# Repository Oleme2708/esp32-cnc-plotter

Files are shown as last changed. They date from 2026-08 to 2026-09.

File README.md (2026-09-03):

# ✏️ ESP32 CNC Plotter






A fully 3D-printed three-axis CNC drawing machine controlled by an ESP32.  
The machine receives G-code from **Universal Gcode Sender (UGS)** and uses **Grbl_ESP32** to control three 28BYJ-48 unipolar stepper motors through ULN2003 driver boards.

# Note

This project was developed using **PlatformIO in Visual Studio Code**.

The mechanical structure is based on the **Simple Arduino CNC Plotter** design by **DonTheMaker**.  
The original design uses a fully 3D-printed mechanical structure together with stepper motors and a small number of fasteners.

For my build, I replaced the original controller setup with an **ESP32**, configured **Grbl_ESP32** for three unipolar stepper motors, and used **Universal Gcode Sender** to manually control the axes and run G-code file.

I also designed two additional washer parts because the screws available to me did not fit the original assembly as required.

> CAD source link: https://makerworld.com/en/models/2889145-simple-arduino-cnc-plotter?from=search#profileId-3227843

# Demo

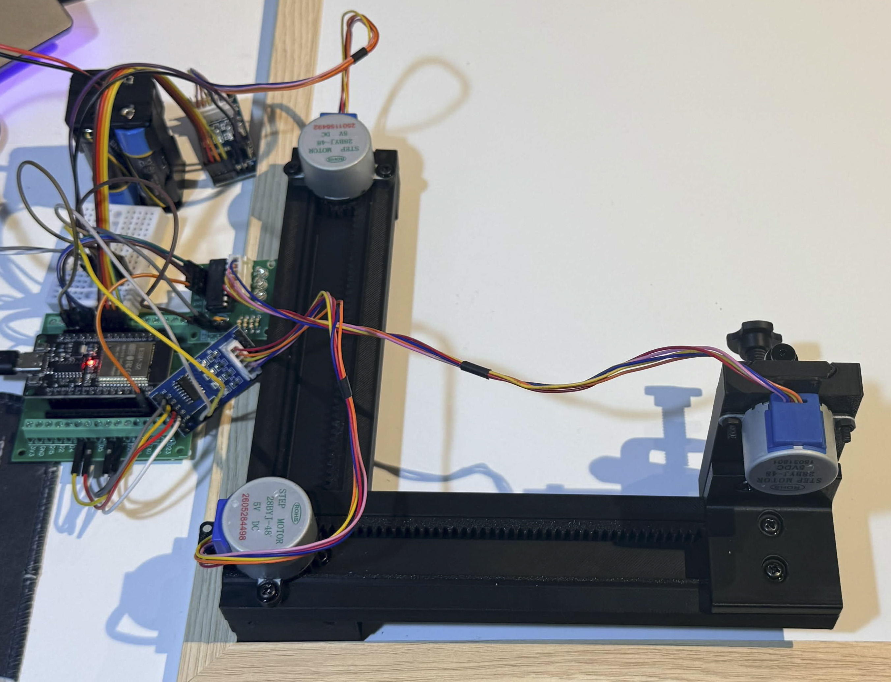
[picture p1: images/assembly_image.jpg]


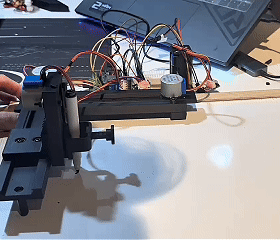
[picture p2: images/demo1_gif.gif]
CNC Plotter Demo


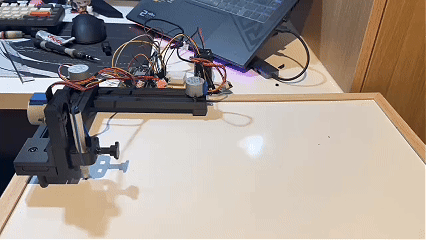
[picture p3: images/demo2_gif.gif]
CNC Plotter Demo


# Project overview

This project is a small three-axis CNC pen plotter built around an ESP32 and three 28BYJ-48 5V stepper motors.

The machine is controlled through the following system:

```text
G-code file
     |
     v
Universal Gcode Sender (UGS)
     |
     USB / Serial
     v
ESP32 + Grbl_ESP32
     |
     v
ULN2003 motor drivers
     |
     v
28BYJ-48 stepper motors
     |
     v
X / Y / Z mechanical movement
     |
     v
Pen drawing on paper
```

UGS is used to:

+ Calibration and setup
+ Jog the X, Y and Z axes manually
+ Send individual G-code commands
+ Preview G-code paths
+ Load complete G-code files
+ Start and monitor drawing jobs

The X and Y axes control the pen position on the paper, while the Z axis lifts and lowers the pen.

The current usable drawing area is approximately:

```text
125 mm × 125 mm
```

# Features

+ Fully 3D-printed CNC plotter structure
+ Three-axis motion control
+ ESP32-based controller
+ Three 28BYJ-48 unipolar stepper motors
+ Three ULN2003 motor drivers
+ Custom Grbl_ESP32 machine configuration
+ G-code control using Universal Gcode Sender
+ Manual X/Y/Z jogging through UGS
+ G-code preview and job execution
+ PlatformIO development

# Hardware

+ ESP32 development board
+ 3 × 28BYJ-48 5V stepper motors
+ 3 × ULN2003 stepper motor driver boards
+ External regulated 5V power supply
+ Fully 3D-printed CNC plotter structure
+ Pen / marker
+ Jumper wires
+ USB cable
+ Small number of M4 screws / fasteners used in the mechanical assembly
+ 2 × custom 3D-printed washers added for my build

# Software

+ Visual Studio Code
+ PlatformIO
+ Universal Gcode Sender (UGS)
+ Grbl_ESP32

## Universal Gcode Sender

UGS is the main interface used to control this CNC plotter from the computer.

Official website:

https://winder.github.io/ugs_website/

UGS is used for manual jogging, sending G-code commands, previewing tool paths, and running complete G-code jobs.

## Grbl_ESP32

This project uses the open-source Grbl_ESP32 firmware by Bart Dring and contributors.

Firmware source:

https://github.com/bdring/Grbl_Esp32

The complete Grbl_ESP32 firmware is not copied into this repository.  
Only the custom configuration used for this machine is included.

# Firmware configuration

The custom machine configuration can be found in:

```text
firmware/esp32_cnc_plotter_config.h
```

The configuration enables unipolar motor control and assigns four ESP32 GPIO pins to each motor.

# ESP32 pin configuration 
These pin are wired this way to avoid important pins that might cause error
## X axis

| Motor phase | ESP32 GPIO |
|---|---:|
| Phase 0 | GPIO 26 |
| Phase 1 | GPIO 25 |
| Phase 2 | GPIO 33 |
| Phase 3 | GPIO 32 |

## Y axis

| Motor phase | ESP32 GPIO |
|---|---:|
| Phase 0 | GPIO 19 |
| Phase 1 | GPIO 16 |
| Phase 2 | GPIO 17 |
| Phase 3 | GPIO 18 |

## Z axis

| Motor phase | ESP32 GPIO |
|---|---:|
| Phase 0 | GPIO 14 |
| Phase 1 | GPIO 27 |
| Phase 2 | GPIO 13 |
| Phase 3 | GPIO 23 |

# Wiring diagram
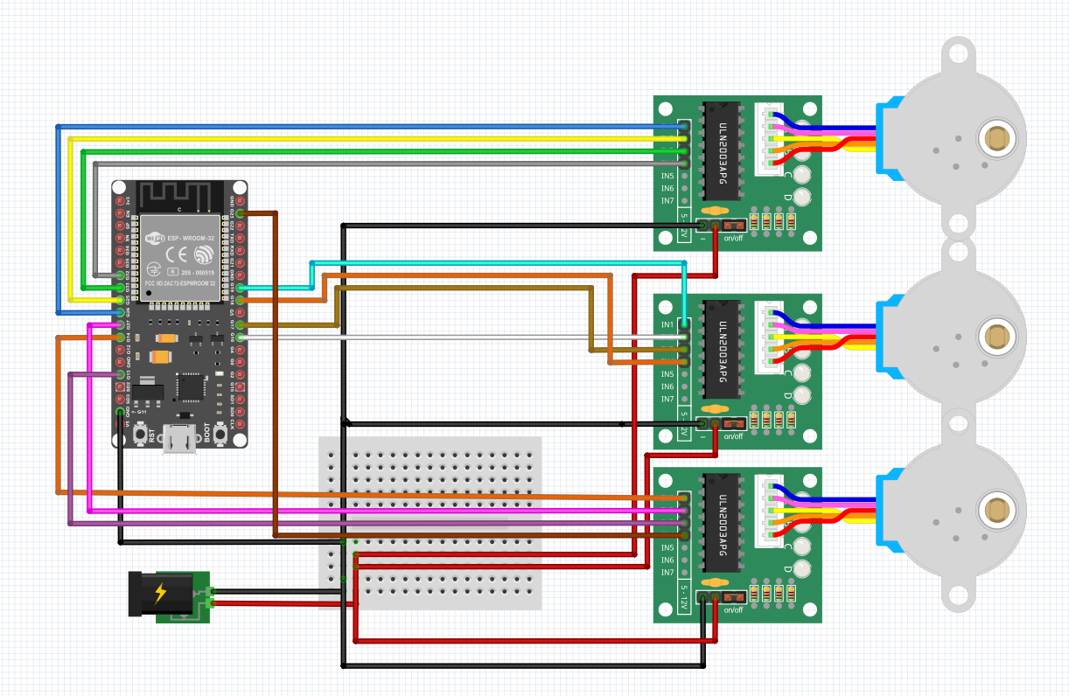
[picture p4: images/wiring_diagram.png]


# Axis direction

The physical orientation of the current machine is:

```text
                 X- (up)
                    ↑
                    |
Y- (left)  ←--------+--------→  Y+ (right)
                    |
                    ↓
                 X+ (down)
```

Therefore:

+ `X+` = move down
+ `X-` = move up
+ `Y+` = move right
+ `Y-` = move left

The Z axis controls pen up / pen down movement.

Because of the physical layout:

```text
Paper vertical direction   = Machine X axis
Paper horizontal direction = Machine Y axis
```

This orientation has to be considered when generating G-code.

# G-code

The machine receives G-code from UGS through the ESP32 serial connection.

Some basic commands used in this project are:

```gcode
G21
G90
G91
```

Where:

```text
G21 = millimetres
G90 = absolute positioning
G91 = relative positioning
```

Example relative movement:

```gcode
G91

G1 X10 F150
G1 X-10 F150

G1 Y10 F150
G1 Y-10 F150
```

With the current machine orientation:

```text
X10  = move 10 mm down
X-10 = move 10 mm up

Y10  = move 10 mm right
Y-10 = move 10 mm left
```

The final drawing tests mainly use `G91` relative positioning because it is easier to start a drawing from a manually selected position without relying on a fixed machine origin.

Custom G-code files are stored in:

```text
gcode/
```

# Pen control

The Z axis lifts and lowers the pen.

Example:

```gcode
G91

G1 Z-1 F20
G1 Y30 F200
G1 Z1 F20
```

Only a small Z movement is required.

The exact pen-up and pen-down distance depends on the mechanical adjustment of the pen holder.

# Calibration

The main Grbl axis calibration settings are:

```text
$100 = X-axis steps/mm
$101 = Y-axis steps/mm
$102 = Z-axis steps/mm
```

The X axis has been tested at approximately:

```text
$100 = 100 steps/mm
```

The calibration method used is:

run G1 X50 F100 to draw a line
measure the line to check the accuracy. The line should be 5cm, changing the value of $100 if different value are drew. repeat for other axis

# Speed testing

The 28BYJ-48 is a small geared stepper motor, so the maximum reliable speed is limited.

Feed rate was increased gradually during testing:

```text
F100
F150
F200
F250
F300
```

If a motor begins to:

+ vibrate without moving
+ lose steps
+ make abnormal sounds
+ fail to return to the original position

the feed rate should be reduced.

# How to Use

## 1. Set up Grbl_ESP32

Clone or download Grbl_ESP32:

https://github.com/bdring/Grbl_Esp32

Copy:

```text
firmware/esp32_cnc_plotter_config.h
```

into:

```text
Grbl_Esp32/src/Machines/
```

Configure the build to use:

```text
-DMACHINE_FILENAME=esp32_cnc_plotter_config.h
```

Then build and upload the firmware to the ESP32 using PlatformIO.

## 2. Connect the machine to UGS

Download / install Universal Gcode Sender:

https://winder.github.io/ugs_website/

Then:

+ Connect the ESP32 to the computer using USB
+ Open UGS
+ Select the correct serial port
+ Set the baud rate to `115200`
+ Connect using GRBL mode

The PlatformIO Serial Monitor must be closed before connecting through UGS because only one application can use the serial port at a time.

## 3. Test the axes

Use the UGS Jog Controller to test:

+ X+
+ X-
+ Y+
+ Y-
+ Z+
+ Z-

Start with a small movement such as 1 mm or 10 mm.

## 4. Run a drawing

+ Move the pen to a safe starting position
+ Make sure enough X/Y travel is available
+ Make sure the pen starts raised
+ Load the `.gcode` file into UGS
+ Check the preview
+ Run a dry test if necessary
+ Start the job

# CAD

The main mechanical structure is based on:

**Simple Arduino CNC Plotter — DonTheMaker**

Platform:

**MakerWorld / Bambu Studio Online Models**

> https://makerworld.com/en/models/2889145-simple-arduino-cnc-plotter?from=search#profileId-3227843

The plotter is designed so that almost the complete mechanical structure can be produced using a 3D printer.

My build uses the original printed mechanism as the base, but the electronics, controller, firmware configuration, wiring, calibration, G-code workflow, and troubleshooting were completed separately for the ESP32 version.

## Additional CAD parts

I designed two simple washer parts for this build because the screws available to me did not fit the original assembly correctly.

Files:

```text
CAD/Washer_1.5mm.STL
CAD/Washer_2mm.STL
```

These washers were used as simple spacing / fitting adjustments during assembly.

The original plotter model is stored in:

```text
CAD/Simple_CNC_Plotter.3mf
```

# What I learned

+ How basic CNC motion control works
+ How G-code controls physical machine movement
+ How to use Universal Gcode Sender to manually control a CNC machine
+ How to preview and execute G-code jobs using UGS
+ How to configure Grbl_ESP32 for a custom machine
+ How to use Grbl_ESP32 with 28BYJ-48 unipolar motors
+ How motor phase order affects direction and movement
+ How to assign ESP32 GPIO pins to three motor axes
+ How to build and upload ESP32 firmware using PlatformIO
+ How to communicate with a CNC controller through serial
+ How to calibrate motion using steps/mm
+ How to test feed rates and detect step loss
+ How to troubleshoot motor-driver and wiring problems
+ How mechanical alignment affects drawing accuracy
+ How to simplify G-code for more reliable motion
+ How to adapt an existing mechanical design to different electronics and available hardware

# Errors and lesson learned

+ **Motor appeared not to move or vibrating:** 
the feed rate was too low, so the motor was moving extremely slowly rather than being completely stopped.
the ULN2003 driver board power connection was disconnected. Checking the driver power fixed the issue.
faulty jumper wires caused unreliable motor phase signals. Replacing the wires restored normal movement.

+ **Motor moved correctly in one direction but vibrated in reverse:** one motor phase connection was unreliable.

+ **Axis direction was incorrect:** with the 28BYJ-48 unipolar motors, the motor phase order and physical wiring directly affect direction.

+ **Drawing orientation was incorrect:** the physical X axis of this machine is vertical while the Y axis is horizontal. The G-code generation logic had to be changed to match the actual machine.

+ **Absolute G-code was harder to manage during testing:** incorrect start positions could cause the machine to travel farther than expected. Relative `G91` paths made the final demo easier to control.

+ **Complex automatically generated G-code was difficult to debug:** some generated files contained thousands of small movements. Simpler centre-line drawings using mainly `G0` and `G1` commands were easier to test.

+ **Arc commands caused errors during some tests:** line-based paths were used where possible for a more reliable demo.

+ **The frame can move while drawing:** because the structure is lightweight and mostly 3D printed, the machine can slide during axis movement if it is not fixed to the table.

+ **Pen contact is not always consistent:** the current pen holder has limited vertical compliance, so pen pressure can change across the drawing area.

# Current limitations

+ No limit switches
+ Open-loop stepper control with no position feedback
+ Lightweight 3D-printed frame can move during operation
+ Pen pressure can vary with mechanical alignment
+ Drawing speed is limited by the 28BYJ-48 geared stepper motors

# Future improvements

+ Add a spring-loaded or floating pen holder
+ Fix the machine to a more rigid base
+ Add limit switches
+ Improve cable management
+ Improve mechanical rigidity
+ Perform more accurate X/Y calibration
+ Optimise G-code paths
+ Test higher reliable feed rates
+ Consider migrating from Grbl_ESP32 to FluidNC in a future version

# Credits

## Mechanical design

**Simple Arduino CNC Plotter**  
Designer: **DonTheMaker**  
Platform: **MakerWorld**

> https://makerworld.com/en/models/2889145-simple-arduino-cnc-plotter?from=search#profileId-3227843

## Grbl_ESP32

This project uses the open-source **Grbl_ESP32** firmware by Bart Dring and contributors:

https://github.com/bdring/Grbl_Esp32

## Universal Gcode Sender

The machine is controlled using **Universal Gcode Sender**:

https://winder.github.io/ugs_website/

## Grbl

Grbl_ESP32 is based on the original Grbl CNC firmware by Sungeun K. Jeon and contributors:

https://github.com/grbl/grbl

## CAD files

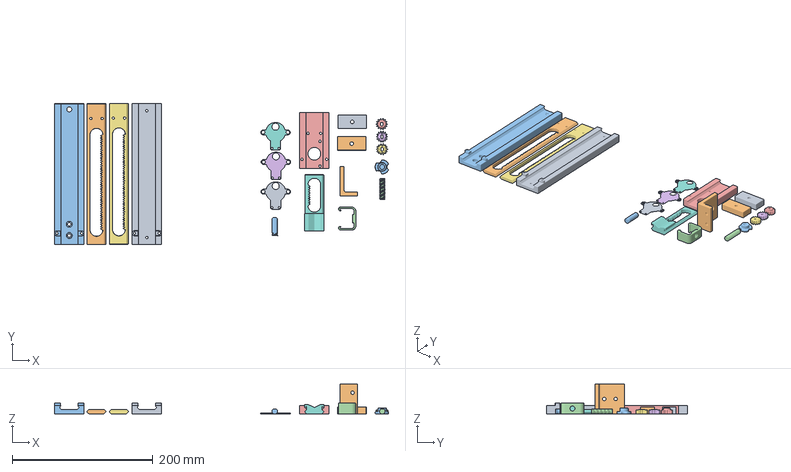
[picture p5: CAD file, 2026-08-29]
CAD/Simple_CNC_Plotter.3mf
473.9 x 200.6 x 42.0 mm
Channel.stl x 3
Angle.stl
Clamp Bridge.stl
Body1.stl x 3
Rack.stl x 3
Knob.stl
Stud.stl
Spur Gear 14 teeth.stl
Spur Gear (14 teeth).stl x 2
Spacer.stl x 2
Slider Foot v3.stl

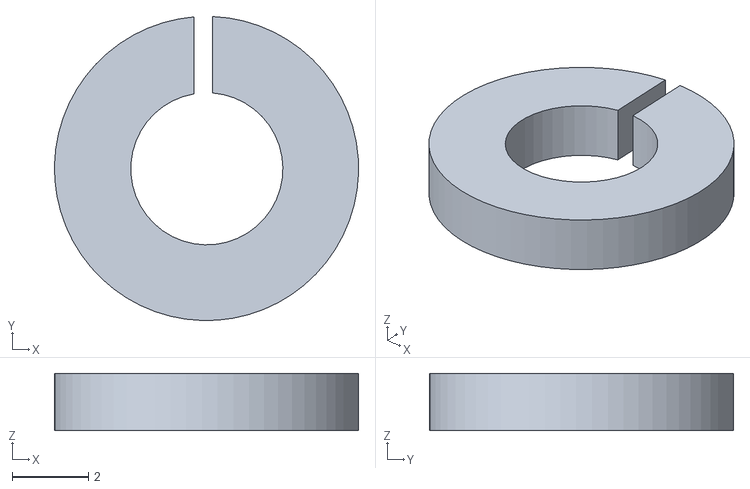
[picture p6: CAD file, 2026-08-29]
CAD/Washer_1.5mm.STL
8.00 x 7.99 x 1.50

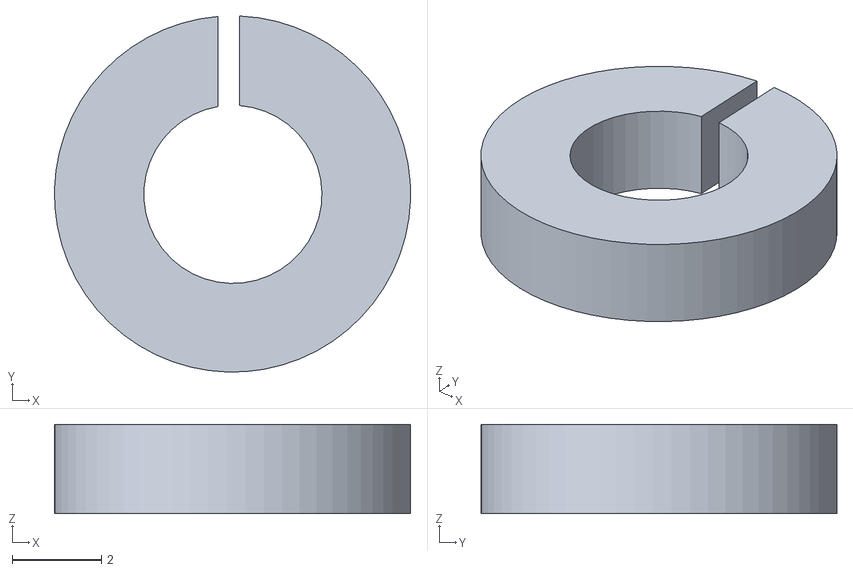
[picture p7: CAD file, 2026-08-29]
CAD/Washer_2mm.STL
8.00 x 7.99 x 2.00

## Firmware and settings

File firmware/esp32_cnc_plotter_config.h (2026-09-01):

#pragma once

#define MACHINE_NAME "ESP32 CNC Plotter"

#ifdef USE_RMT_STEPS
#    undef USE_RMT_STEPS
#endif

// ======================
// X AXIS - 28BYJ-48
// ======================

#define X_UNIPOLAR

#define X_PIN_PHASE_0 GPIO_NUM_26
#define X_PIN_PHASE_1 GPIO_NUM_25
#define X_PIN_PHASE_2 GPIO_NUM_33
#define X_PIN_PHASE_3 GPIO_NUM_32

// ======================
// Y AXIS - 28BYJ-48
// ======================

#define Y_UNIPOLAR

#define Y_PIN_PHASE_0 GPIO_NUM_19
#define Y_PIN_PHASE_1 GPIO_NUM_16
#define Y_PIN_PHASE_2 GPIO_NUM_17
#define Y_PIN_PHASE_3 GPIO_NUM_18

// ======================
// Z AXIS - 28BYJ-48
// ======================

#define Z_UNIPOLAR

#define Z_PIN_PHASE_0 GPIO_NUM_14
#define Z_PIN_PHASE_1 GPIO_NUM_27
#define Z_PIN_PHASE_2 GPIO_NUM_13
#define Z_PIN_PHASE_3 GPIO_NUM_23
